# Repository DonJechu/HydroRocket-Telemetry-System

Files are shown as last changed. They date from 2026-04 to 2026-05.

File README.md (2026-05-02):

# 🚀 Atl-I Flight Computer — v2.0

> **Avionics system for experimental water-powered rockets.**
> Real-time telemetry · Triple-redundant apogee detection · Wi-Fi ground station · 7-state flight FSM






---

## 📋 Table of Contents

1. [Project Overview](#project-overview)
2. [Research Context](#research-context)
3. [Hardware Architecture](#hardware-architecture)
4. [Avionics Bay — Design Evolution](#avionics-bay--design-evolution)
5. [Firmware — Flight State Machine](#firmware--flight-state-machine)
6. [Sensor Processing & Filters](#sensor-processing--filters)
7. [Telemetry System](#telemetry-system)
8. [Repository Structure](#repository-structure)
9. [Build & Flash](#build--flash)
10. [Known Issues & v4 Integration Status](#known-issues--v4-integration-status)

---

## Project Overview

**HYDRO-1** is a flight computer designed for water-powered PET bottle rockets. It is the hardware platform for ongoing research into **EMI mitigation in aerospace wiring harnesses**, using the Poynting Vector framework to validate field-based signal integrity strategies in a real high-vibration environment.

The system provides:
- **Real-time telemetry** over Wi-Fi WebSocket at 10 Hz
- **Triple-redundant apogee detection** (velocity zero-crossing + altitude drop + safety timeout)
- **Hardware IIR pressure filtering** on BMP280 to suppress aerodynamic transients
- **Parachute deployment** via servo at confirmed apogee

> 🚀 **Status:** First flight scheduled — April 28, 2026. Integration complete. Ground testing passed. This repository documents the complete design process including failures, iterations, and corrections — which is the engineering record.

---

## Research Context

This project serves as the experimental platform for ongoing research on EMI mitigation in aerospace wiring harnesses, using a field-theoretic approach (Poynting Vector framework). Research paper in preparation — to be submitted to IEEE

### Core Thesis

Classical intuition treats wires as "pipes" for energy. This is incorrect. The actual energy carrier is the electromagnetic field surrounding the conductor, described by the **Poynting Vector**:

$$\mathbf{S} = \frac{1}{\mu_0}(\mathbf{E} \times \mathbf{B}) \quad \left[\frac{\text{W}}{\text{m}^2}\right]$$

Electrons drift at mere millimeters per second — governed by the **Drude model**:

$$v_d = \frac{I}{nqA}$$

while energy propagates at near light speed through the *external* field. This has direct consequences for EMI: **crosstalk is not a wire problem, it is a field geometry problem.**

### Why this rocket?

The HYDRO-1 wiring harness is intentionally designed in two configurations:
1. Unshielded parallel runs (power + signal lines adjacent) — baseline EMI scenario
2. Twisted pair + separated routing — field-confined scenario

In-flight telemetry data will be compared between configurations to measure real crosstalk impact on sensor fidelity under high-vibration, high-EMI conditions (motor PWM, servo switching, Wi-Fi RF).

---

## Hardware Architecture

### Component Stack

| Component | Part | Role |
|---|---|---|
| **Microcontroller** | ESP32-DEVKIT-V1 (30-pin) | Main processor, Wi-Fi AP, WebSocket server |
| **IMU** | MPU-6050 compatible module | 9-axis IMU — note: physical chip is newer variant, library-compatible — configured for ±16G |
| **Barometer** | BMP280 | Altitude via pressure — hardware IIR filter enabled |
| **Power Regulation** | MT3608 Boost Converter | 3.7V LiPo → 5V regulated for ESP32 VIN |
| **Decoupling** | 100µF electrolytic + 100nF ceramic | MT3608 output bulk filter + IMU VCC bypass |
| **Battery** | LiPo 103040 — 3.7V / 1200mAh / 4.44Wh | Flight power supply |
| **Actuator** | Standard servo (GPIO 13) | Parachute deployment mechanism |

### I²C Bus

Both MPU-6050 and BMP280 share the I²C bus:

| Signal | ESP32 Pin |
|---|---|
| SDA | GPIO 21 |
| SCL | GPIO 22 |
| MPU-6050 Address | 0x68 |
| BMP280 Address | 0x76 |

### Power Path

```
LiPo 3.7V ──► MT3608 Boost ──► 5V ──► ESP32 VIN ──► 3.3V LDO ──► Sensors
                (adj. to 5V)
```

> **Schematic:** See [`hardware/Schematic_HidroRocket_v0_2026-04-26.pdf`](hardware/Schematic_HidroRocket_v0_2026-04-26.pdf)

---

## Avionics Bay — Design Evolution

The avionics bay has gone through three major design iterations. Each failure was documented and fed directly into the next version. This is the engineering record.

### Version Comparison

| Parameter | v1 | v2 | v3 | v4 (current) |
|---|---|---|---|---|
| **Height** | 118.5 mm | 118 mm | 102 mm | TBD |
| **Base OD** | 52 mm | 81 mm | 80.9 mm | TBD |
| **Printed Mass** | 33.01 g | 66.62 g | 46.22 g | 25.63 |
| **Pieces** | 1 | 2 | 2 | 1 |
| **PCB mount** | Screwed direct | Slide rail | Slide rail (revised) | TBD |
| **Battery space** | None | Insufficient | In revision | TBD |
| **Fits 1.35L bottle** | ❌ | ❌ | ❌ | ✅ |
| **Architecture** | 1 piece | 2 pieces | 2 pieces | 1 piece |
| **Structure** | Solid shell | Rail + shell | Honeycomb panel | Truss / celosía |

> *Masses are slicer estimates (PETG, no supports). Final printed mass will differ.*

---

### v1 — Structural Baseline
 
**Goal:** Minimum viable bay. One-piece design, direct PCB mount.
 
**Result — Failed integration:**
- PCB mounting nuts and standoff contractions caused mechanical interference; the board could not be seated flush
- No dedicated battery compartment — LiPo placement undefined
- Ring dimensions incorrect: OD too small to fit inside a 1.35L Coca-Cola PET bottle (~85mm ID required)
- Single-piece design meant any revision required reprinting the entire part
**Mass:** 33.01 g | **Height:** 118.5 mm | **OD:** 52 mm
 
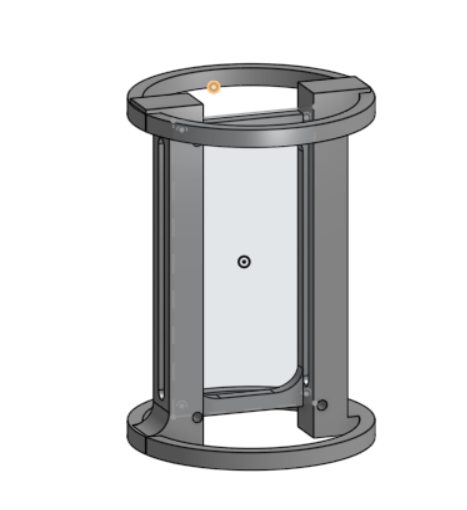
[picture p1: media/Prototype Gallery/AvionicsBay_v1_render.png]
AvionicsBay v1 Render

 
---
 
### v2 — Rail System
 
**Goal:** Solve PCB access problem. Introduce modularity.
 
**Key change:** Split into two parts — a structural sled that mounts to the bottle, and a PCB carrier plate that slides into a rail. This means PCB changes only require reprinting the carrier plate, not the full bay.
 
**Result — Too heavy:**
- Rail + structural shell geometry increased mass to 66.62 g (+100% vs v1)
- Battery space still insufficient for 103040 LiPo cell (30×40×10 mm)
- OD corrected but not validated against physical bottle measurement
**Mass:** 66.62 g | **Height:** 118 mm | **OD:** 81 mm
 
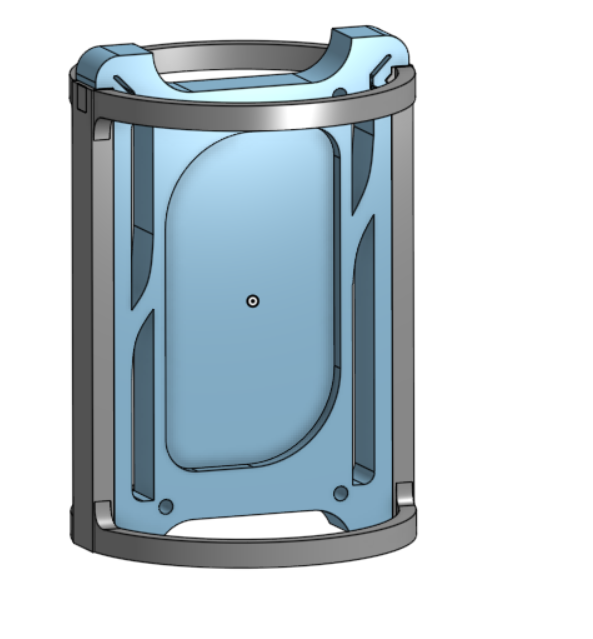
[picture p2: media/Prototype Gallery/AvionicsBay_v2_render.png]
AvionicsBay v2 Render

 
---
 
### v3 — Mass-Optimized Honeycomb (Current Alpha)
 
**Goal:** Reduce mass below 40g while keeping v2's rail modularity. Introduce honeycomb infill geometry on the main panel.
 
**Key changes:**
- Reduced height by 16 mm (102 mm total)
- Honeycomb cutout pattern on main structural panel (mass reduction + ventilation)
- Maintained two-piece rail system from v2
**Failures documented (v3.0 Alpha):**
1. **Mechanical:** Nut/standoff interference on PCB mount — same root cause as v1, not fully resolved
2. **Volumetric:** Battery compartment still does not accommodate LiPo 103040 (30×40×10 mm) + cable routing (minimum 5–8 mm egress space required)
3. **Geometric:** OD not validated against physical bottle. Nominal 80.9 mm but actual 1.35L bottle ID varies 84–87 mm by batch — must be measured with calipers before fixing in CAD
4. **Structural:** Print fracture during support removal on thin-wall sections (<2 mm) with Tree support configuration on Bambu Lab P2S
**Mass:** 46.22 g | **Height:** 102 mm | **OD:** 80.9 mm
 
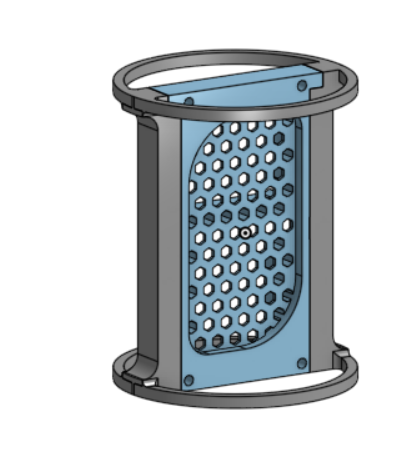
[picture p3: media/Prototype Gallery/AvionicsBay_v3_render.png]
AvionicsBay v3 Render


 ### v4 — Single-Piece Truss Architecture (Current)

**Goal:** Eliminate over-engineering. Return to single-piece design with truss/celosía geometry for maximum mass reduction while maintaining structural integrity.

**Key changes:**
- Single-piece design — removes rail interface, assembly complexity, and inter-part tolerance issues
- Truss skeleton replaces solid honeycomb panel — material only where structurally necessary
- Estimated model mass: 23.92 g (slicer, no supports) — best result across all versions

**Print history:**
- `ABv4.0` — Failed. Top Z distance 0mm caused supports to fuse to structure. Removed with damage.
- `ABv4.1` — Successful. Top Z distance corrected to 0.25mm, Normal supports, threshold 30°. Structure intact post-support removal.

**Design rationale:** Previous versions (v2, v3) introduced modularity to solve PCB access — but added mass and complexity. v4 returns to v1's simplicity with v3's mass consciousness. Less is more.

**Integration status:** PCB assembly fits inside 1.35L bottle. ✅ Pending: secure mounting method and mass measurement.

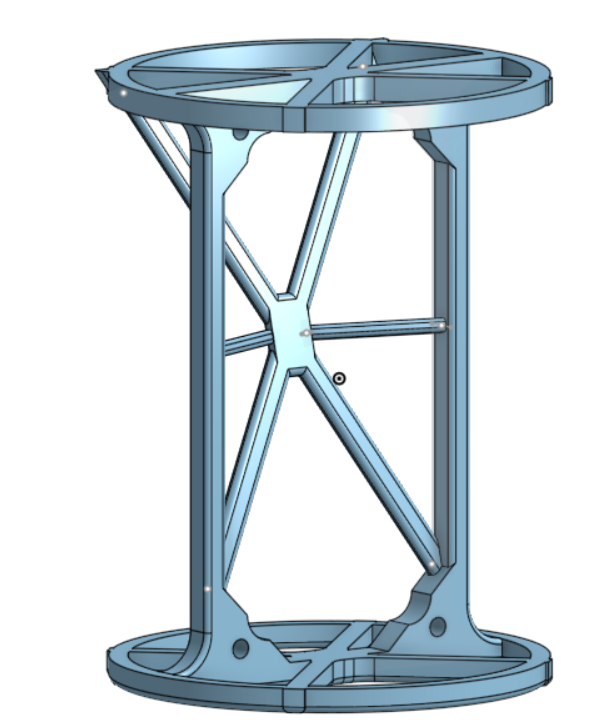
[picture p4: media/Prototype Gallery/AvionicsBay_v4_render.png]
AvionicsBay v4 Render


### PCB — Physical Assembly
 
| Bare board (v1 iteration) | Full assembly with ESP32 + sensors |
|---|---|
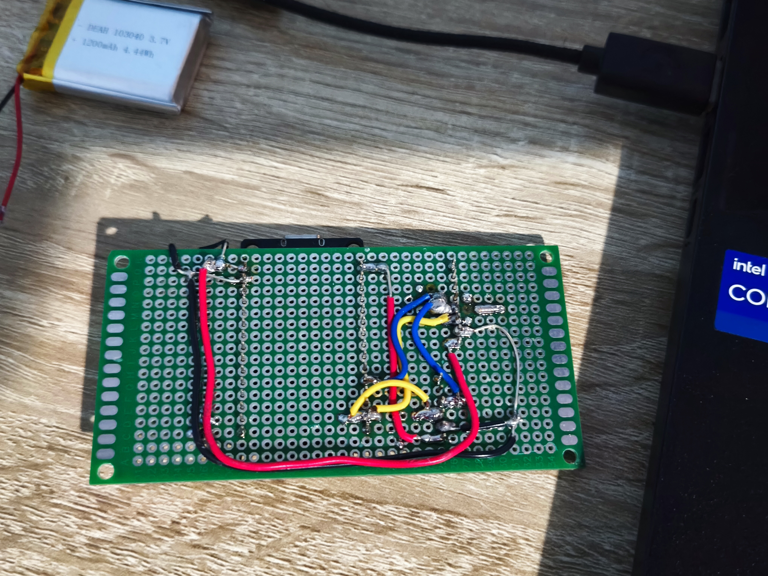
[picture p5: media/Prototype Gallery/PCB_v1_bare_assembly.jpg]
PCB bare
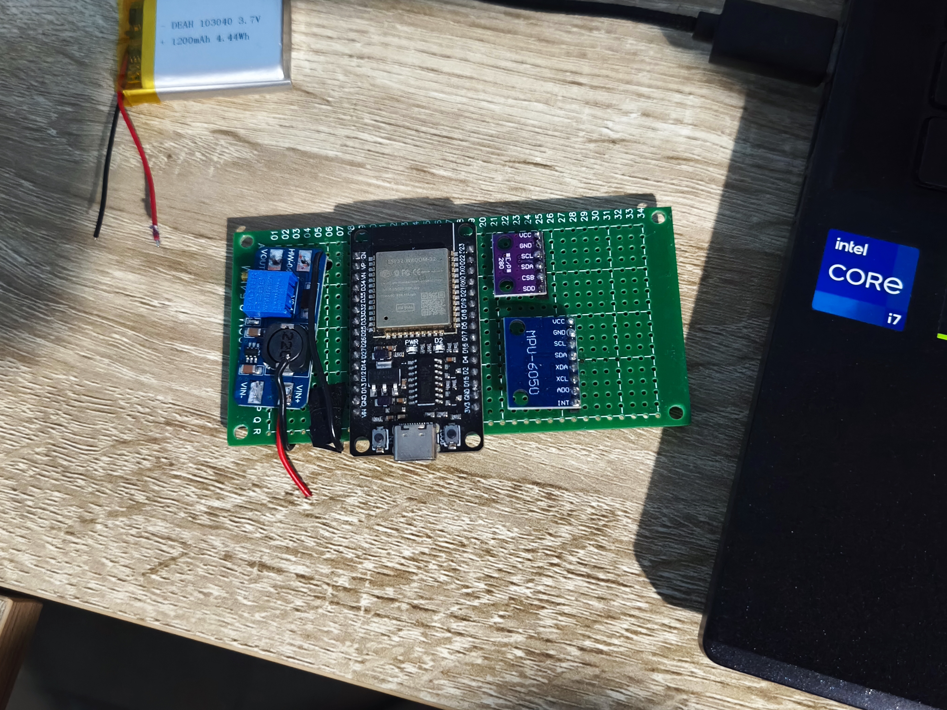
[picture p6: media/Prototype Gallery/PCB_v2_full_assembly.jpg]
PCB full
|  |  |
 
---

## Firmware — Flight State Machine

The flight computer implements a 7-state finite state machine. States `ARMED` and `IGNITION` are defined in the enum for future remote-arming via the ground station dashboard but are not yet active in the switch logic.

```
                    gForce ≥ 2.5G
                   (4 consecutive)
  ┌──────────┐ ─────────────────────► ┌──────────┐
  │ STANDBY  │                        │  ASCENT  │
  └──────────┘                        └──────────┘
                                           │
                          ┌────────────────┼────────────────┐
                          │                │                │
                    vel ≤ 0           alt drops        timeout
                   (5 samples)         1.0m (4s)       12,000 ms
                          │                │                │
                          └────────────────┼────────────────┘
                                           ▼
                                      ┌──────────┐
                                      │  APOGEE  │  servo → 90°
                                      └──────────┘
                                           │
                                           ▼
                                      ┌──────────┐
                                      │ DESCENT  │
                                      └──────────┘
                                           │
                                    alt < 0.75 m
                                           │
                                           ▼
                                      ┌──────────┐
                                      │ LANDING  │
                                      └──────────┘
```

### State Descriptions

| State | ID | Entry Condition | Action |
|---|---|---|---|
| `STANDBY` | 0 | Boot | Transmit telemetry, wait for liftoff |
| `ARMED` | 1 | *(future: ground station command)* | Arm pyro / deployment circuit |
| `IGNITION` | 2 | *(future: remote trigger)* | Log ignition timestamp |
| `ASCENT` | 3 | gForce ≥ 2.5G × 4 samples | Track maxAltitude, evaluate apogee |
| `APOGEE` | 4 | Triple-redundant (see below) | `servo.write(90)` — deploy parachute |
| `DESCENT` | 5 | Post-apogee | Monitor altitude, transmit |
| `LANDING` | 6 | altitude < 0.75 m | Stop flight log (LittleFS — pending) |

### Triple-Redundant Apogee Detection

Apogee is the most safety-critical event. Three independent methods must confirm it:

**Method 1 — Velocity Zero-Crossing (Primary)**

The most reliable indicator from rocketry literature. When vertical velocity transitions from positive to zero or negative:

$$v(t) = v(t-1) \cdot 0.85 + \frac{\Delta h}{\Delta t} \cdot 0.15 \leq 0 \quad \text{(5 consecutive samples)}$$

**Method 2 — Altitude Drop (Backup)**

If the filtered altitude falls more than 1.0 m below the recorded maximum:

$$h_{current} < h_{max} - \Delta h_{apogee} \quad (\Delta h_{apogee} = 1.0\text{ m}, \; 4 \text{ confirmations})$$

**Method 3 — Absolute Timeout (Safety)**

If neither primary nor backup triggers within 12 seconds of liftoff confirmation, the parachute deploys unconditionally. This prevents the rocket from impacting the ground without a deployed chute in case of sensor failure.

---

## Sensor Processing & Filters

### BMP280 — Dual IIR Filtering

Aerodynamic turbulence creates pressure transients that corrupt altitude readings. The BMP280 includes a hardware IIR filter that is enabled at maximum coefficient:

```cpp
bmp.setSampling(
  MODE_NORMAL,
  SAMPLING_X2,   // Temperature oversampling
  SAMPLING_X16,  // Pressure oversampling — maximum resolution
  FILTER_X16,    // Hardware IIR — maximum smoothing
  STANDBY_MS_1   // ~27 ms update rate
);
```

A second software IIR filter is applied in the main loop:

$$h_{filtered}[n] = \alpha \cdot h_{filtered}[n-1] + (1-\alpha) \cdot h_{raw}[n]$$

With $\alpha = 0.8$ for flight (responsive to 15–20 m/s dynamics). Note: this will appear noisy in static indoor testing — that is the correct and expected behavior.

### Pressure Calibration

At boot, 300 pressure samples are averaged over ~3 seconds to establish a local ground-level reference:

$$P_{base} = \frac{1}{300}\sum_{i=1}^{300} P_i$$

This must be performed with the rocket stationary on the launch pad.

### MPU-6050 — G-Force & Orientation

The IMU is configured for the high-G environment of a water rocket launch:

```cpp
mpu.setAccRange(MPU9250_ACC_RANGE_16G);   // ±16G
mpu.setGyrRange(MPU9250_GYRO_RANGE_2000); // ±2000°/s
```

G-force magnitude:

$$G = \sqrt{a_x^2 + a_y^2 + a_z^2}$$

Euler angles (from raw accelerometer, no Kalman filter yet — planned for v3.1 firmware):

$$\text{pitch} = \arctan\!\left(\frac{a_x}{\sqrt{a_y^2 + a_z^2}}\right) \cdot \frac{180°}{\pi}$$

$$\text{roll} = \arctan\!\left(\frac{a_y}{a_z}\right) \cdot \frac{180°}{\pi}$$

---

## Telemetry System

The ESP32 creates a Wi-Fi Access Point (`SSID: GANNET`) and serves a WebSocket server on port 81. The ground station connects and receives JSON packets at 10 Hz:

```json
{
  "alt":      42.3,
  "vel":      12.1,
  "accel":    3.47,
  "pitch":    -2.1,
  "roll":     0.8,
  "yaw":      0.0,
  "temp":     28.4,
  "pressure": 1009.2,
  "phase":    3
}
```

| Field | Unit | Description |
|---|---|---|
| `alt` | m | Filtered altitude above launch point |
| `vel` | m/s | Vertical velocity (positive = ascending) |
| `accel` | G | Total acceleration magnitude |
| `pitch` | ° | Nose-up/down angle |
| `roll` | ° | Rotation around longitudinal axis |
| `temp` | °C | Ambient temperature (BMP280) |
| `pressure` | hPa | Absolute pressure |
| `phase` | 0–6 | Current flight state ID |

---

## Ground Station — HYDRO-1 GS
 
The ground station is a separate React + Vite web application that connects to the flight computer over WebSocket and visualizes all telemetry in real time.
 
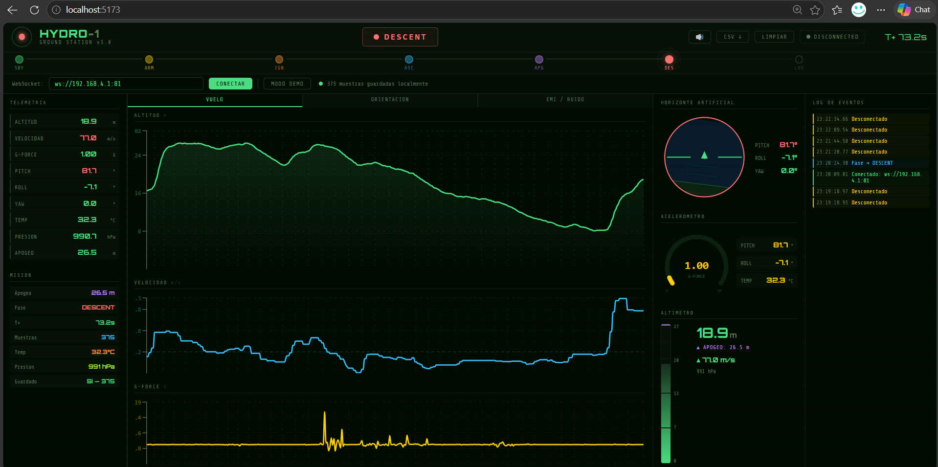
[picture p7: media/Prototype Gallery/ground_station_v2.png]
Ground Station Dashboard

 
### Features
 
| Feature | Description |
|---|---|
| **3D Attitude View** | Real-time 3D rocket model that rotates with live pitch, roll, and yaw data |
| **Flight Phase Tracker** | Left panel shows all 7 states (STANDBY → ARMED → IGNITION → ASCENT → APOGEE → DESCENT → RECOVERY), highlighting the active state |
| **Live Telemetry Panel** | Right panel — altitude (m), velocity (m/s), G-force, pitch, roll, yaw, temperature (°C), pressure (hPa) |
| **Session Records** | Tracks max altitude, max velocity, max G, and mission elapsed time (T+) |
| **Altitude & Velocity Charts** | Real-time graphs at the bottom of the screen |
| **WiFi Connect / Demo Mode** | Connect to the ESP32 AP or run a simulated flight for testing without hardware |
| **Status Bar** | Persistent bottom bar showing pitch, roll, temperature, and pressure at a glance |
 
### Tech Stack
 
```
React + Vite        — UI framework (localhost:5173 in dev)
WebSocket (port 81) — Real-time data stream from ESP32
Three.js            — 3D rocket attitude visualization
```
 
### Connection Flow
 
```
ESP32 (AP: GANNET) ──► WebSocket ws://192.168.4.1:81 ──► Ground Station
                              10 Hz JSON packets
```

 Ground Station Demo
> **Ground Station Repository:** [HYDRO-1-Ground-Station](https://github.com/DonJechu/HYDRO-1-Ground-Station)
>  
---

## Repository Structure

```
HydroRocket-Telemetry-System/
├── firmware/
│   └── HydroRocket.ino          # Main flight computer firmware (v2.0)
├── hardware/
│   └── Schematic_HidroRocket_v0_2026-04-20.pdf
├── mechanical/
│   ├── AvionicsBay_v1 - Bay_Structure.stl
│   ├── AvionicsBay_v1 - Sled.stl
│   └── AvionicsBay_v1.step
├── media/
│   └── Prototype Gallery/       # Photos and renders
└── README.md
```

---

## Build & Flash

### Dependencies (Arduino IDE / PlatformIO)

```
MPU9250_WE          by Wolfgang Ewald
Adafruit BMP280     by Adafruit
ESP32Servo          by Kevin Harrington
WebSockets          by Markus Sattler
WiFi                (ESP32 built-in)
```

### Flash Steps

1. Open `firmware/HydroRocket.ino` in Arduino IDE
2. Select board: **ESP32 Dev Module**
3. Select the correct COM port
4. Upload
5. Open Serial Monitor at **115200 baud**
6. Wait for `=== READY FOR FLIGHT ===`
7. Connect to Wi-Fi: `SSID: GANNET` / `Password: 1234`
8. Open ground station on port 81

### Pre-Launch Checklist

- [ ] Battery charged (LiPo 103040, 3.7V nominal)
- [ ] Rocket stationary on pad during 3-second pressure calibration
- [ ] Serial monitor confirms `Base Pressure: ~1013 hPa` (±15 hPa acceptable)
- [ ] Ground station WebSocket connected and receiving data
- [ ] Servo verified at 0° (parachute closed)
- [ ] `phase: 0` (STANDBY) confirmed on dashboard

---

## Known Issues & v4 Integration Status

### Mechanical — v4 Targets

| Item | Status |
|---|---|
| OD validation against physical bottle | ⚠️ Pending — measure with calipers post-print |
| PCB mounting clearance | ⚠️ TBD — single piece, verify nut interference |
| LiPo 103040 mounting | ⚠️ No dedicated compartment — open truss design requires external mounting solution |
| Support removal on truss geometry | ✅ Resolved — Top Z 0.25mm, Normal supports, threshold 30° |

### Firmware — Planned

- [ ] Kalman filter for pitch/roll (replace raw atan2)
- [ ] LittleFS black-box data logging (close file on LANDING state)
- [ ] `ARMED` / `IGNITION` state integration with React ground station
- [ ] In-flight EMI measurement logging (crosstalk baseline vs. shielded config)

### Research — Pending

- [ ] Simscape MATLAB model: mutual inductance between power and signal traces
- [ ] Experimental comparison: unshielded vs. twisted-pair wiring harness

---

## Author

**Jesús Alberto Perea García**
Mechatronics Engineering Student — IEST Anáhuac, Tamaulipas
Member: IEEE Student Branch · Vértice Excellence Program
[github.com/DonJechu](https://github.com/DonJechu) · jesus.perea@iest.edu.mx

*This project is part of ongoing research on EMI in aerospace avionics systems under field-theoretic analysis (Poynting Vector framework). Mentored by Ing. Oscar (aerospace specialist).*

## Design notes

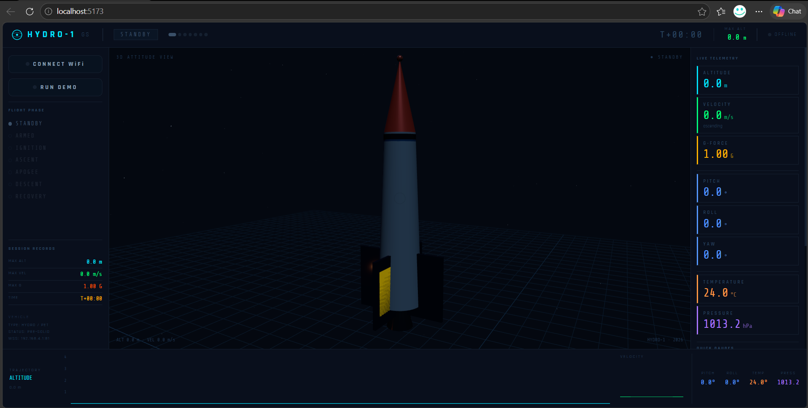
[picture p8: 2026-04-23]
media/Prototype Gallery/ground_station_v1.2.png

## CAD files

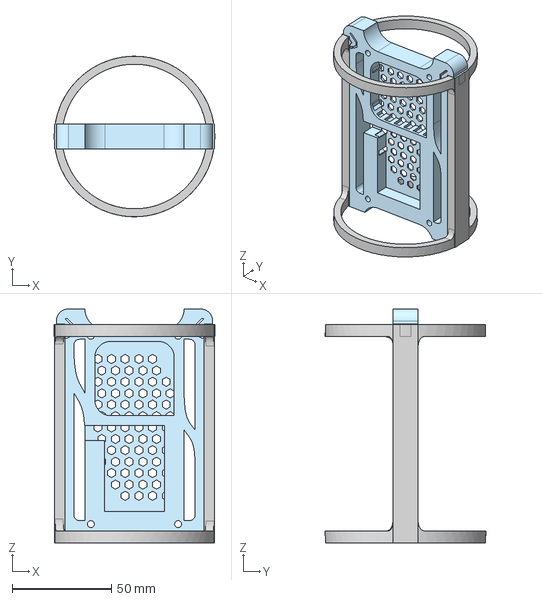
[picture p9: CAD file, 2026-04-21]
mechanical/AvionicsBay_v2.5.step
81.0 x 81.0 x 118.0 mm

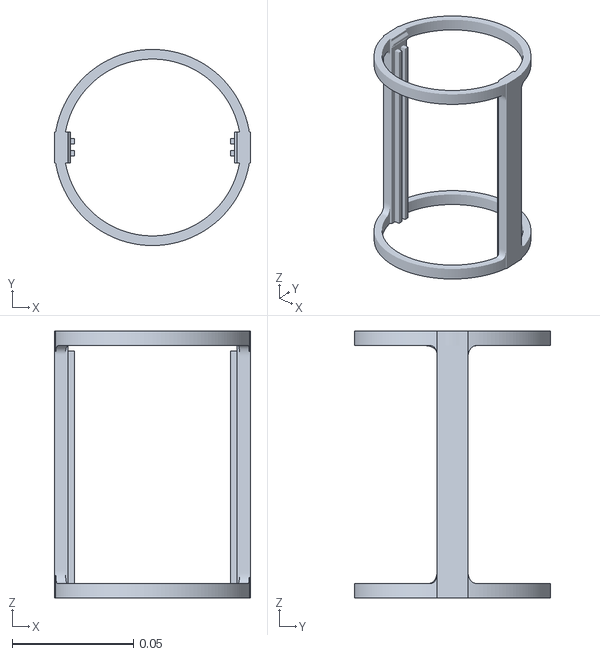
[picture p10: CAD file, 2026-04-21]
mechanical/AvionicsBay_v2.5 - Bay_Structure.stl
0.081 x 0.081 x 0.11

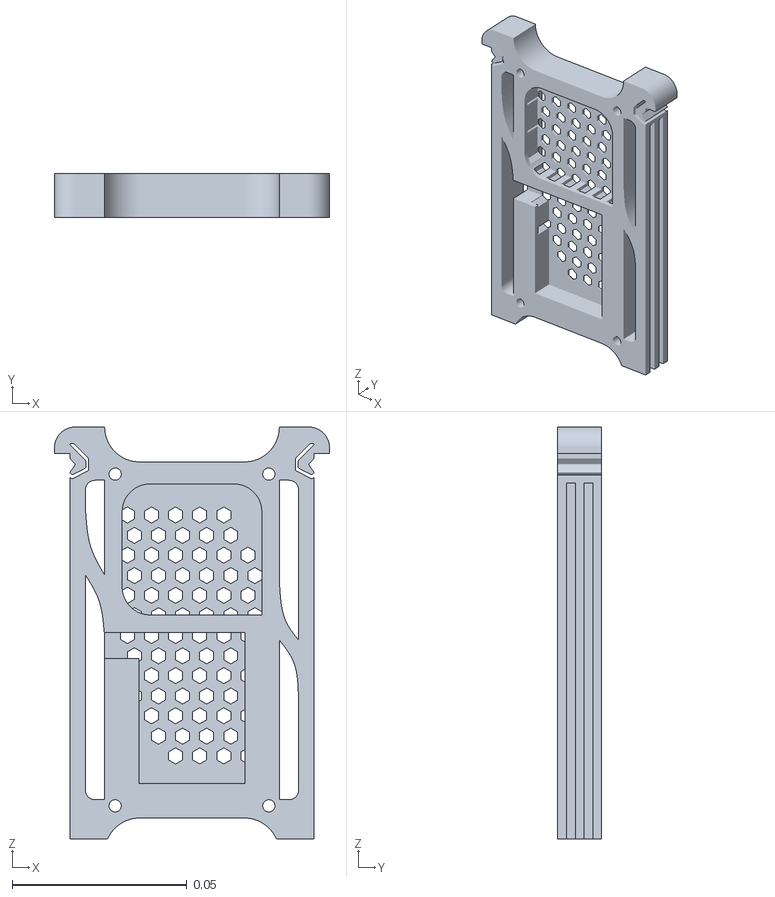
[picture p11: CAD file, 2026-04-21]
mechanical/AvionicsBay_v2.5 - Sled.stl
0.0788 x 0.0127 x 0.118

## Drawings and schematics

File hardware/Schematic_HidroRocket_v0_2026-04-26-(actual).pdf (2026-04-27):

A | A

1

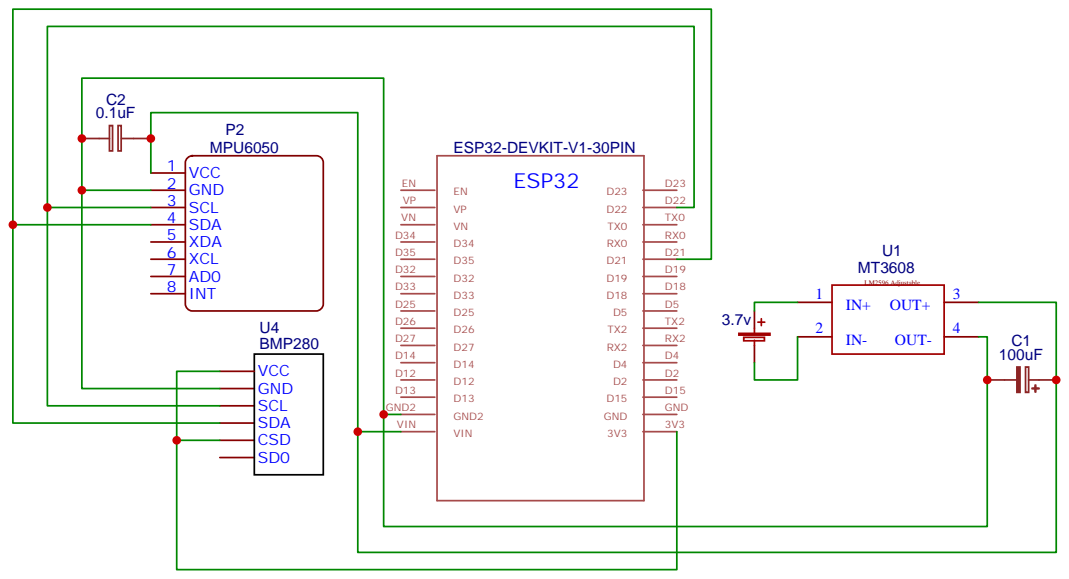
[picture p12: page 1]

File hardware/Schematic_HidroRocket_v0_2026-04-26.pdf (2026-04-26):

A | A

1

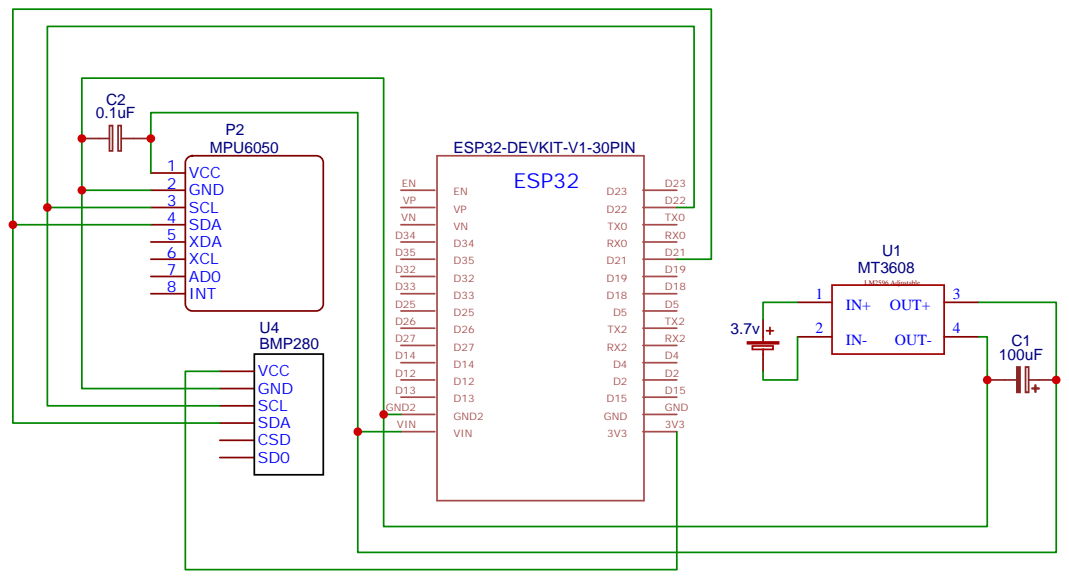
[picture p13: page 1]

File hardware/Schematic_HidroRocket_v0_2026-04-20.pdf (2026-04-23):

A | A

1

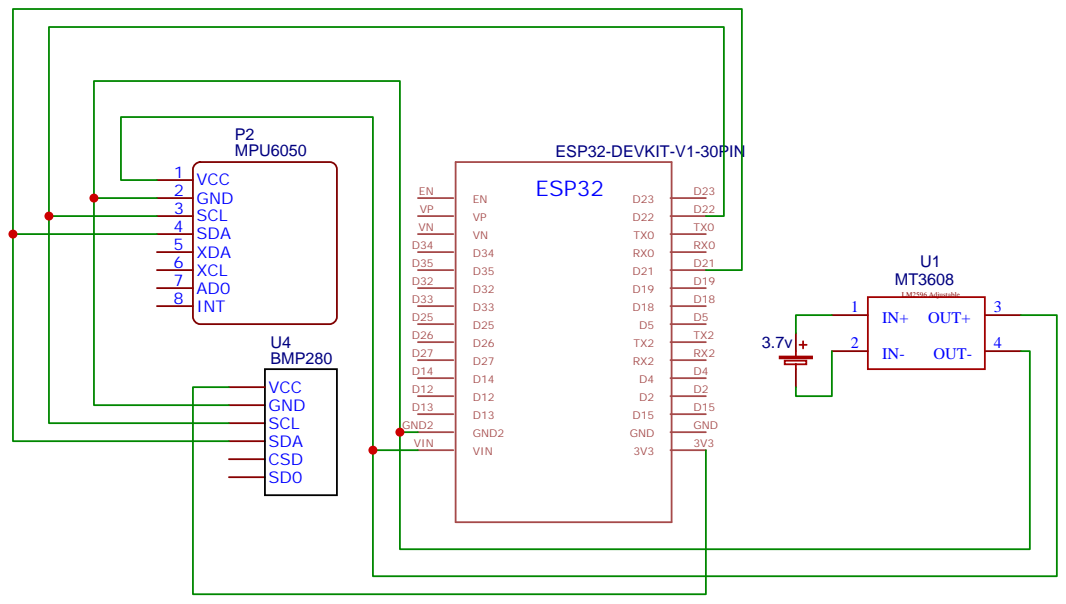
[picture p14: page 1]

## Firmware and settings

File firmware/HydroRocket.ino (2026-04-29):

#include <Wire.h>
#include <MPU9250_WE.h>
#include <Adafruit_BMP280.h>
#include <ESP32Servo.h>
#include <WiFi.h>
#include <WebSocketsServer.h>

// ================================================================
//  HYDRO-1 FLIGHT COMPUTER  —  v2.0  FLIGHT-READY
//  Filters and thresholds calibrated for real flight, not for
//  static indoor testing.
// ================================================================

// ------------- 1. Config -------------
const char* ssid     = "GANNET";
const char* password = "1234";
#define PIN_SDA    21
#define PIN_SCL    22
#define PIN_SERVO  13
#define MPU_ADDR   0x68

// ------------- Flight Thresholds (adjust according to your rocket) -------
// Typical PET water rocket: ~15-20 m/s peak, ~30-60 m apogee
#define LIFTOFF_G            2.5f   // Gs to confirm liftoff
#define LIFTOFF_CONFIRMS     4      // Required consecutive samples
#define APOGEE_VEL_THRESHOLD 0.0f   // Velocity <= 0 = apogee
#define APOGEE_CONFIRMS      5      // Consecutive samples to confirm apogee
#define APOGEE_ALT_DROP      1.0f   // Meters of drop as backup
#define APOGEE_ALT_CONFIRMS  4      // Confirmations for altitude drop
#define MIN_ALTITUDE_LAUNCH  3.0f   // Minimum altitude before searching for apogee
#define LANDING_ALT_M        0.75f  // Landing altitude
#define ASCENT_TIMEOUT_MS    12000  // Safety timeout in ASCENT (ms)

// ------------- 2. Objects -------------
MPU9250_WE    mpu = MPU9250_WE(MPU_ADDR);
Adafruit_BMP280     bmp;
Servo               parachute;
WebSocketsServer    webSocket = WebSocketsServer(81);

// ------------- 3. Globals & States -------------
float          basePressure      = 1013.25f;
int            currentState      = 0;
float          currentAltitude   = 0.0f;
float          filteredAltitude  = 0.0f;
float          gForce            = 0.0f;
float          maxAltitude       = 0.0f;
unsigned long lastTelemetryTime = 0;
const int      telemetryInterval = 100;  // 10 Hz telemetry
float          lastAltitude      = 0.0f;
unsigned long lastTime           = 0;
float          velocity          = 0.0f;
float          pitch             = 0.0f;
float          roll              = 0.0f;

// Confirmation counters (anti-transient)
int           liftoffCounter    = 0;
int           apogeeVelCounter  = 0;
int           apogeeAltCounter  = 0;

// Timing
unsigned long ascentStartTime   = 0;
unsigned long lastBmpRead       = 0;
const int      bmpInterval       = 40;   // 25 Hz BMP280

// ================================================================
//  Flight State — synchronized with Ground Station
// ================================================================
enum FlightStates {
  STANDBY   = 0,
  ARMED     = 1,
  IGNITION  = 2,
  ASCENT    = 3,
  APOGEE    = 4,
  DESCENT   = 5,
  LANDING   = 6
};

// ================================================================
//  SETUP
// ================================================================
void setup() {
  Serial.begin(115200);
  Wire.begin(PIN_SDA, PIN_SCL);

  // WiFi AP + WebSockets
  WiFi.softAP(ssid, password);
  WiFi.setTxPower(WIFI_POWER_8_5dBm);
  webSocket.begin();
  Serial.println("=== HYDRO-1 FLIGHT COMPUTER BOOT ===");

  // MPU9250
  if (!mpu.init()) {
    Serial.println("[ERROR] MPU9250 Init Failed");
  }
  mpu.setAccRange(MPU9250_ACC_RANGE_16G);
  mpu.setGyrRange(MPU9250_GYRO_RANGE_2000);
  delay(100);

  // BMP280 — configure hardware IIR filter (key for real flight)
  // The BMP280 has a built-in IIR filter that eliminates turbulence
  // and pressure transients caused by aerodynamic flow.
  if (!bmp.begin(0x76)) {
    Serial.println("[ERROR] BMP280 Init Failed");
  }
  bmp.setSampling(
    Adafruit_BMP280::MODE_NORMAL,
    Adafruit_BMP280::SAMPLING_X2,   // Temperature
    Adafruit_BMP280::SAMPLING_X16,  // Pressure — high resolution
    Adafruit_BMP280::FILTER_X16,    // IIR x16 — maximum hardware smoothing
    Adafruit_BMP280::STANDBY_MS_1   // Update every ~27ms
  );

  // Base pressure calibration — 300 samples, ~3 seconds
  // Perform with the rocket stationary on the pad before arming
  Serial.println("Calibrating base pressure...");
  float sumPressure = 0;
  for (int i = 0; i < 300; i++) {
    sumPressure += bmp.readPressure();
    delay(10);
  }
  basePressure = (sumPressure / 300.0f) / 100.0f;  // Pa → hPa
  Serial.print("Base Pressure: ");
  Serial.print(basePressure);
  Serial.println(" hPa");

  // Servo
  parachute.attach(PIN_SERVO);
  parachute.write(0);  // Closed

  // Initialize state to avoid spikes
  lastTime         = millis();
  lastBmpRead      = millis();
  filteredAltitude = bmp.readAltitude(basePressure);
  lastAltitude     = filteredAltitude;
  currentAltitude  = filteredAltitude;

  Serial.println("=== READY FOR FLIGHT ===");
}

// ================================================================
//  LOOP
// ================================================================
void loop() {
  webSocket.loop();
  readSensors();
  updateLogic();

  int activeInterval = (currentState == STANDBY) ? 1000 : 100;
  if (millis() - lastTelemetryTime >= telemetryInterval) {
    sendData();
    lastTelemetryTime = millis();
  }
}

// ================================================================
//  FLIGHT LOGIC
//  Based on: multi-sample detection to avoid false positives
//  from aerodynamic turbulence (standard in rocket avionics)
// ================================================================
void updateLogic() {
  switch (currentState) {

    // -- STANDBY: wait for liftoff confirmed by N samples
    case STANDBY:
      setCpuFrequencyMhz(80);
      if (gForce >= LIFTOFF_G) {
        liftoffCounter++;
        if (liftoffCounter >= LIFTOFF_CONFIRMS) {
          setCpuFrequencyMhz(240); // Restaurar CPU a máximo para vuelo
          currentState    = ASCENT;
          ascentStartTime = millis();
          maxAltitude     = currentAltitude;
          liftoffCounter  = 0;
          Serial.println("[EVENT] LIFTOFF CONFIRMED");
        }
      } else {
        liftoffCounter = 0;  // Reset if interrupted
      }
      break;

    // -- ASCENT: detect apogee via velocity AND altitude
    case ASCENT:
      if (currentAltitude > maxAltitude) {
        maxAltitude = currentAltitude;
      }

      // Only search for apogee once minimum altitude is exceeded
      // Avoids false detection on the launch rail
      if (maxAltitude < MIN_ALTITUDE_LAUNCH) break;

      // Method 1 (primary): velocity crosses zero → apogee
      // Zero crossing is the most reliable method according to literature
      if (velocity <= APOGEE_VEL_THRESHOLD) {
        apogeeVelCounter++;
        if (apogeeVelCounter >= APOGEE_CONFIRMS) {
          Serial.println("[EVENT] APOGEE — velocity zero crossing");
          openParachute();
          break;
        }
      } else {
        apogeeVelCounter = 0;
      }

      // Method 2 (backup): altitude drop from the maximum
      if (currentAltitude < (maxAltitude - APOGEE_ALT_DROP)) {
        apogeeAltCounter++;
        if (apogeeAltCounter >= APOGEE_ALT_CONFIRMS) {
          Serial.println("[EVENT] APOGEE — altitude drop backup");
          openParachute();
          break;
        }
      } else {
        apogeeAltCounter = 0;
      }

      // Method 3 (safety): absolute timeout
      if (millis() - ascentStartTime > ASCENT_TIMEOUT_MS) {
        Serial.println("[SAFETY] TIMEOUT — forcing parachute deployment");
        openParachute();
        break;
      }
      break;

    case DESCENT:
      if (currentAltitude < LANDING_ALT_M) {
        currentState = LANDING;
        Serial.println("[EVENT] LANDING DETECTED");
      }
      break;

    case LANDING:
      break;
  }
}

void openParachute() {
  parachute.write(90);
  currentState     = DESCENT;
  apogeeVelCounter = 0;
  apogeeAltCounter = 0;
}

// ================================================================
//  LECTURA DE SENSORES
//  Filtros calibrados para vuelo real:
//  - Alpha más alto (0.8) → más responsivo a cambios reales rápidos
//  - Sin deadband de velocidad → no suprimir lecturas reales en vuelo
//  - En pruebas estáticas se verá ruidoso; en vuelo se verá suave
// ================================================================
void readSensors() {
  unsigned long currentTime = millis();
  float dt = (currentTime - lastTime) / 1000.0f;
  lastTime = currentTime;

  // BMP280 rate limiting
  if (millis() - lastBmpRead >= bmpInterval) {
    float rawAlt = bmp.readAltitude(basePressure);

    // Filtro IIR por software — alpha=0.8 para vuelo real
    // (responsivo a cambios de altitud de 15-20 m/s)
    // Nota: en interiores se verá ruidoso — es correcto y esperado
    filteredAltitude = filteredAltitude * 0.8f + rawAlt * 0.2f;

    // Validación: ignorar saltos físicamente imposibles (>100 m en un tick)
    if (abs(filteredAltitude - currentAltitude) < 100.0f) {
      currentAltitude = filteredAltitude;
    }

    // Velocidad — diferencial de altitud filtrada
    if (dt > 0.001f && abs(gForce - 1.0f) > 0.05f) {
      float rawVel = (currentAltitude - lastAltitude) / dt;
      // Alpha=0.85 in flight: smoothes turbulence without hiding real dynamics
      velocity = velocity * 0.85f + rawVel * 0.15f;
    }

    lastAltitude = currentAltitude;
    lastBmpRead  = millis();
  }

  // MPU9250 — G-Force y orientación
  xyzFloat data = mpu.getGValues();
  gForce = sqrt((data.x * data.x) + (data.y * data.y) + (data.z * data.z));

  // data.x es el eje longitudinal del cohete (apunta hacia la nariz)
  pitch = atan2(data.x, sqrt(data.y * data.y + data.z * data.z)) * 180.0f / 3.14159f;
  roll  = atan2(data.y, data.z) * 180.0f / 3.14159f;
}

// ================================================================
//  TELEMETRY — JSON to Ground Station via WebSocket
// ================================================================
void sendData() {
  String json = "{";
  json += "\"t\":"  + String(millis()) + ",";
  json += "\"alt\":"      + String(currentAltitude, 1) + ",";
  json += "\"vel\":"      + String(velocity, 1)        + ",";
  json += "\"accel\":"    + String(gForce, 2)           + ",";
  json += "\"pitch\":"    + String(pitch, 1)            + ",";
  json += "\"roll\":"     + String(roll, 1)             + ",";
  json += "\"yaw\":"      + String(0.0f, 1)             + ",";
  json += "\"temp\":"     + String(bmp.readTemperature(), 1)   + ",";
  json += "\"pressure\":" + String(bmp.readPressure() / 100.0f, 1) + ",";
  json += "\"phase\":"    + String(currentState);
  json += "}";

  webSocket.broadcastTXT(json);
  Serial.println(json);
}

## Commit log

2026-04-21 hw: add initial circuit schematic (ESP32, MPU6050, BMP280)
2026-04-21 mech: add 3D optimized avionics sled with honeycomb pattern
    [AvionicsBay_v1 - Bay_Structure.stl, AvionicsBay_v1 - Sled.stl]
2026-04-21 feat: initial sensor acquisition logic for telemetry
2026-04-21 Add Prototype Gallery directory
2026-04-23 hardware: replace LM2596S with MT3608 boost converter
    - Updated circuit schematic to reflect transition from Buck to Boost regulation.
    - Enabled 1S LiPo (3.7V) power delivery system.
    - Improved power efficiency and reduced total battery mass for the avionics bay.
2026-04-23 Rename Prototype Gallery to Prototypetest
2026-04-23 media: ground_station_demo gif
2026-04-23 media: ground station app
2026-04-23 docs: add Ground Station section with dashboard screenshot and connection flow
2026-04-23 Rename AvionicsBay_v1 - Sled.stl to AvionicsBay_v2.5 - Sled.stl
    [AvionicsBay_v2.5 - Sled.stl]
2026-04-23 Rename AvionicsBay_v1 - Bay_Structure.stl to AvionicsBay_v2.5 - Bay_Structure.stl
    [AvionicsBay_v2.5 - Bay_Structure.stl]
2026-04-26 mechanical: AvionicsBay v4 — single-piece truss architecture, ~23.92g
    Updated version comparison table to include v4 parameters and added details about v4's design rationale and status.
2026-04-26 docs: correct v4 battery mounting — no compartment, open truss design
2026-04-26 mechanical: v4 - cage redesign: skeleton structure, fixed support removal (Top Z 0.25mm), fits 1.35L bottle
2026-04-26 Rename mechanical/AvionicsBay_v2.5 - Bay_Structure.stl to mechanical/archive/AvionicsBay_v2.5 - Bay_Structure.stl
    [AvionicsBay_v2.5 - Bay_Structure.stl]
2026-04-26 Rename mechanical/AvionicsBay_v2.5 - Sled.stl to mechanical/archive/AvionicsBay_v2.5 - Sled.stl
    [AvionicsBay_v2.5 - Sled.stl]
2026-04-26 Add AvionicsBay_v2.5.step file to archive
    [AvionicsBay_v2.5.step]
2026-04-26 hardware: add decoupling capacitor 100nF on MPU-6050 VCC
2026-04-26 docs: update schematic link, repo structure, IMU note, decoupling caps
2026-04-26 mechanical: v4.1 print successful, PCB fits in bottle, update integration status
2026-04-27 firmware: power optimization — WiFi TX reduced, CPU throttle in STANDBY, velocity deadband
2026-04-27 hardware: connect BMP280 CSB pin to 3V3 to prevent SPI mode switching
2026-04-27 docs: added Ground Station section.
2026-04-27 media: ground station
2026-04-28 docs: pre-flight update — status badge, integration complete, repo structure

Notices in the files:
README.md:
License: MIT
